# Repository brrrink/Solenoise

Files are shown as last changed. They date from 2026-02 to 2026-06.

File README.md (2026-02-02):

# Solenoise

## Overview

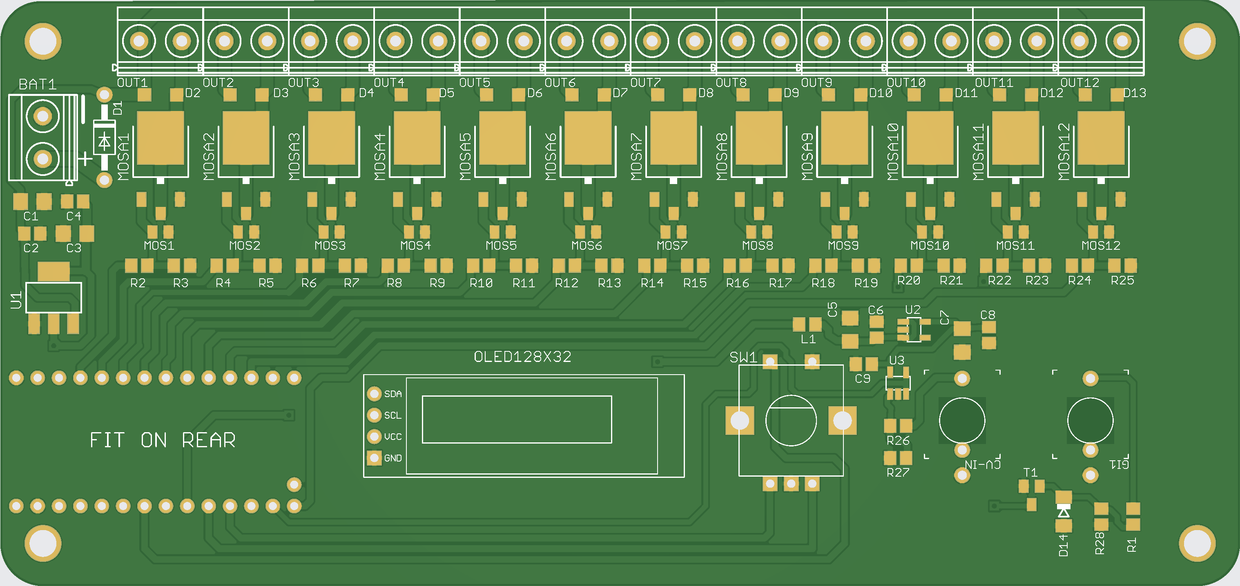
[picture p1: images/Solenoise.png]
solenoise


Solenoise is an open-source hardware and software system designed to transform everyday objects—such as metal plates, wooden surfaces, or architectural elements—into programmable percussive instruments. By leveraging solenoids as electromagnetic actuators, Solenoise enables automated performance, enhancing musical expressivity and extending human capabilities in experimental music, interactive installations, and architectural sound design.

The resurgence of analog modular synthesis, coupled with advancements in physical computing, has inspired this project. Traditional percussive instruments are limited by their fixed physical properties; Solenoise addresses this by providing a versatile control interface that bridges digital and physical realms.

## Key Features

- **Multi-Modal Input Control**: Supports class-compliant MIDI over TRS Mini-Jack, CV/gate inputs with internal logic for simplified and seamless integration with midi capable devices, modular synthesisers, and sequencers.
- **Hardware Simplicity**: Built around a Teensy 4.0 microcontroller with driverless MIDI input and simplified input protection circuits, ensuring compatibility with external devices.
- **Efficient Actuation**: Uses logic-level MOSFETs and protective transistors for safe and efficient operation of inductive loads (solenoids).
- **Configurable Software**: A flexible framework optimises latency and expressivity, with a focus on CV/Trigger input processing along with class compliant MIDI input.
- **Open-Source Ethos**: Unlike proprietary systems (e.g., Polyend Perc, Dada Machines Automat), Solenoise aims to democratise solenoid augmentation and aims to further collaborative innovation.

## Hardware Requirements

- **Microcontroller**: Teensy 4.0 (required for high-speed processing and MIDI support).
- **Solenoids**: Compatible 12V DC solenoids (e.g., push-pull types for striking objects).
- **Power Supply**: 12VDC Powers the development and the solenoids, with internal voltage protection and rectification.

### Input/Output

- **MIDI**: class-compliant MIDI (TRS Type A) via 3.175mm (1/8 inch) 'Mini Jack' input.
- **CV/Gate**: Analog inputs with protection circuits.

## Installation

- **Clone the repository**: git clone https://github.com/brrrink/Solenoise/solenoise.git
- cd solenoise
- Use Platformio to upload firmware to Teensy 4.0, hardware is available to purchase with pre-mounted SMD components or see the Solenoise Production Files folder, for all production ready design files.
- Upload these design files to the PCB manufacturer of your choice, who should be able to provide full soldered SMD PCB's from these files.
- A small number of through-hole components have to be added, these have been minimised to the degree possible to facilitate ease of construction.

## Usage

### Basic Setup

Attach solenoids to objects (e.g., via 3D-printed mounts—in progress enhancement).

Connect inputs:
- MIDI: Plug into a DAW or MIDI controller.
- Gates: Trigger via digital signals from sequencers.
- CV/Trigger: Use modular synth outputs for voltage-based control.

### Example: MIDI-Controlled Percussion

Send MIDI notes to Solenoise via Mini Jack (Type A).

### CV/Gate Integration

CV input controls the allocation of solenoid (12 in total)

Gate input will trigger discrete strikes, supplemented with MIDI for analog and moblie (battery powered) workflows.

### Performance Evaluation

Latency: <5ms for MIDI/CV processing (tested on Teensy 4.0).

Applications: Experimental music (e.g., hybrid human-robot performances), interactive art (e.g., responsive installations), sound design (e.g., architectural acoustics).

## Comparisons to Existing Systems

Solenoise builds on commercial and academic precedents but emphasises accessibility:

- **Commercial**: QRS PNOmation (piano retrofits), Polyend Perc (discontinued drumming machine), Dada Machines Automat (modular but costly), Koma Elektronik Field Kit (electroacoustic with solenoid control), Archil Lab Poet Pilot (object actuation).
- **Academic**: Logos Foundation <Vibi> (robotic vibraphone), Ajay Kapur's MahaDeviBot (percussion robot), Z-Machines guitar-bot.
- **Unique Aspects**: Open-source, CV/Gate inputs extend MIDI, driverless and mobile focussed design. 

## Future Enhancements

- 3D-printed solenoid mounts for easy attachment.
- Wireless control (e.g., via ESP32 integration).
- Expanded inputs/outputs for larger setups.
- Community-contributed presets and mappings.

## Contributing

Contributions are welcome! Fork the repo, create a branch, and submit a pull request. Focus areas:
- Bug fixes in firmware.
- New hardware variants (e.g., Eurorack compatibility).
- Documentation improvements.

Please follow the Code of Conduct.

## License

All non commercial use is approved.

Steal this code.

Commercial use is not approved without consent, contact the authour for more details: anon@anon.com

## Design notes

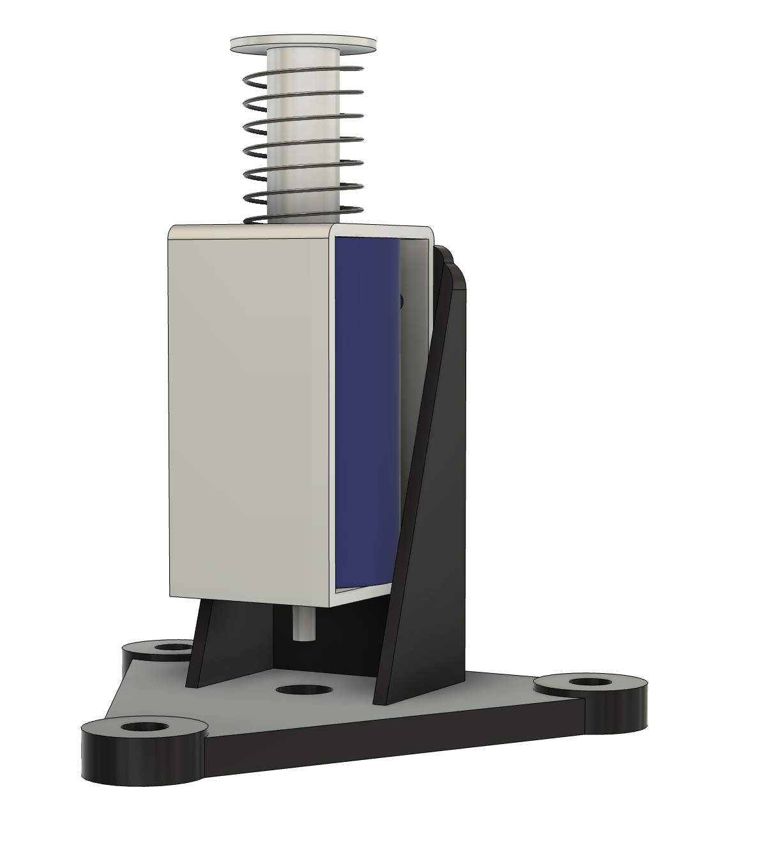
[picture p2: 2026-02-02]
Solenoise Connectors/Kinematic/Kinematic.png

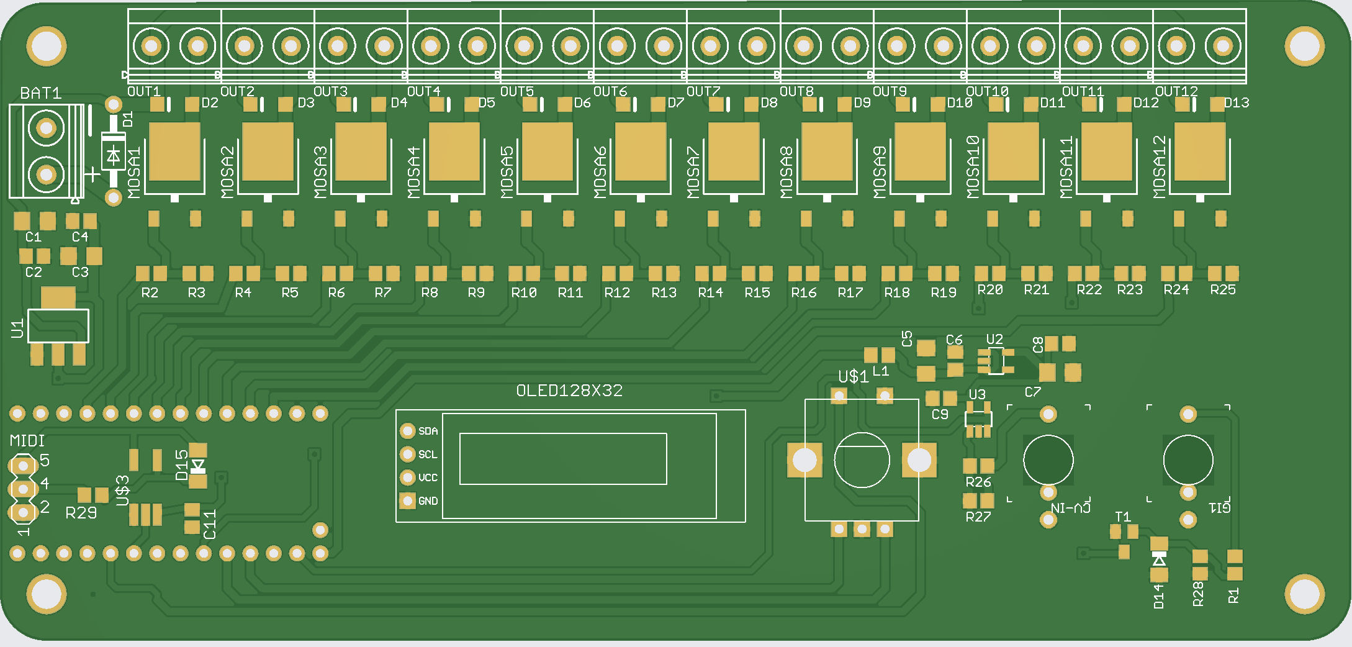
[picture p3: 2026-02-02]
PCB Front.png

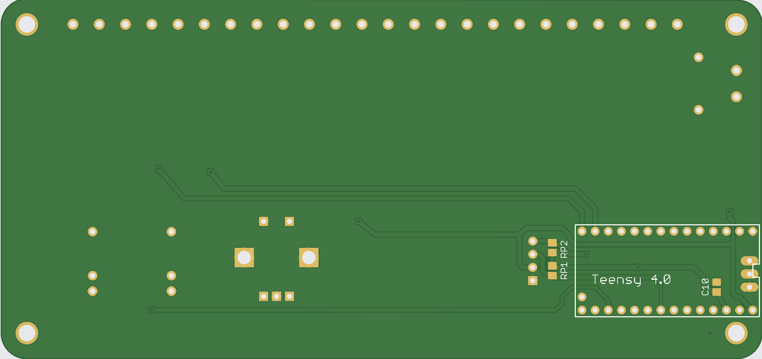
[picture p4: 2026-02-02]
PCB Rear.png

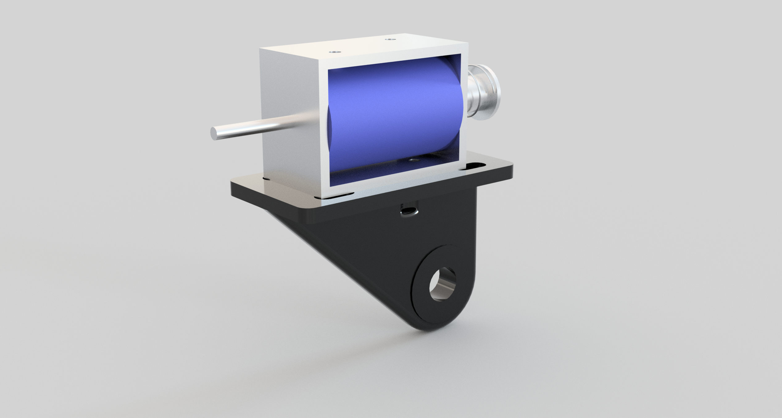
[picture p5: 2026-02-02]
Solenoise Connectors/Mic Clip/Mic Clip Small Render.png

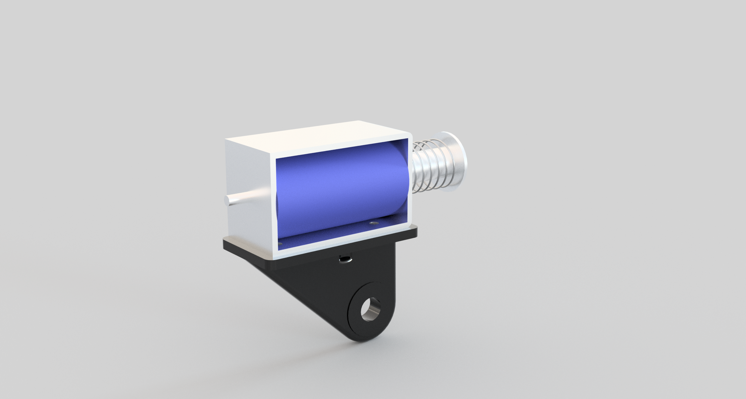
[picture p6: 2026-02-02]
Solenoise Connectors/Mic Clip/Mic Clip Large Render.png

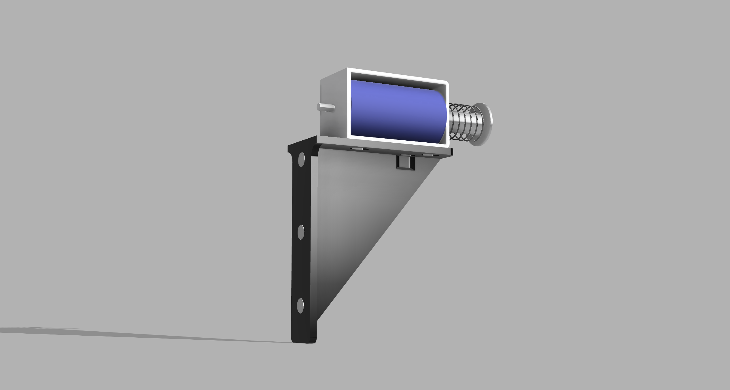
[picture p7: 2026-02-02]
Solenoise Connectors/Magnetic L/Magnetic L-Connector v0.png

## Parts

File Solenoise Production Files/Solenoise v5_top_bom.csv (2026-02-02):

Qty | Designator | Footprint | Comment | LCSC #
4 | C1, C3, C5, C7 | C1206 | 10u | C77092
6 | C2, C4, C6, C8, C9, C11 | C0805 | 100n | C28233
1 | C10 | C0805 | 470n | C13967
12 | D2, D3, D4, D5, D6, D7, D8, D9, D10, D11, D12, D13 | SOD123 | 1N5819HWQ | C460770
2 | D14, D15 | SOD80C | PMLL4148 | C78613
1 | L1 | R0805 | 10uH | C223171
12 | MOSA1, MOSA2,MOSA3, MOSA4, MOSA5, MOSA6, MOSA7, MOSA8, MOSA9, MOSA10, MOSA11, MOSA12 | FQD13N06LTM | FQD13N06LTM | C236914
15 | R1, R3, R5, R7, R9, R11,R13, R15, R17, R19, R21, R23, R25, R26, R28 | R0805 | 100k | C96346
13 | R2, R4, R6, R8, R10, R12, R14, R16, R18, R20, R22, R24, R29 | R0805 | 220R | C114519
1 | R30 | R0805 | 470R | C114564
1 | R27 | R0805 | 200K | C114235
1 | T1 | SOT23 | BC847 | C8664
1 | U$3 | SO-6-5 | TLP2361 | C6285467
1 | U1 | SOT223 | LM1117IMPX-5.0 | C41202
1 | U2 | SOT23-5 | ADP150-3.3 | C29149
1 | U3 | MCP6001 | MCP6001U | C21403

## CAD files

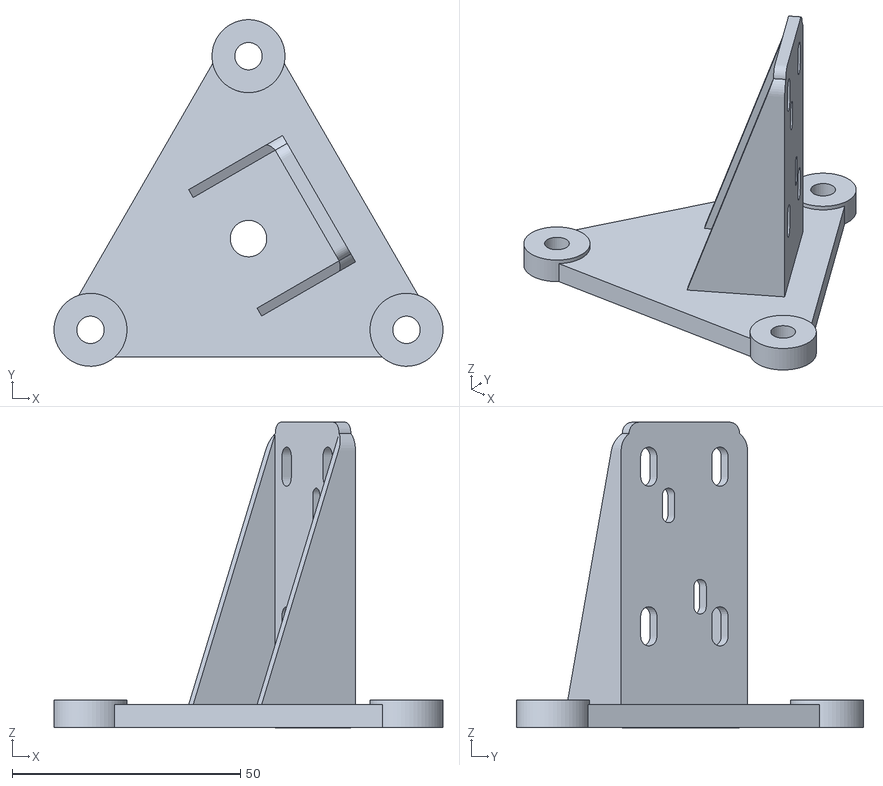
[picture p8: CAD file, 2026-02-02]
Solenoise Connectors/Kinematic/Kinematic Stand.stl
85.3 x 76.0 x 67.0

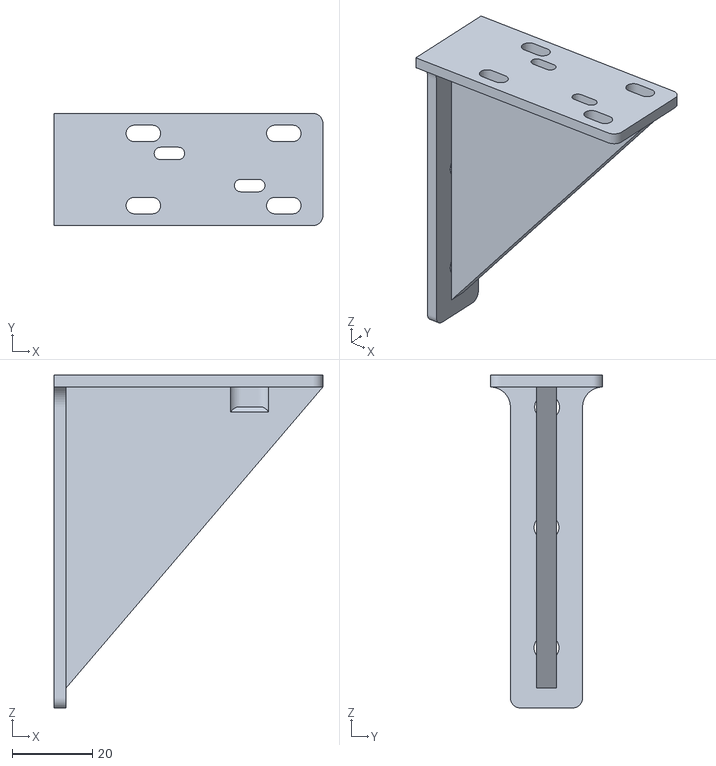
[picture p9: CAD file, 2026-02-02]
Solenoise Connectors/Magnetic L/Magnetic L-Connector.stl
67.0 x 28.0 x 83.0

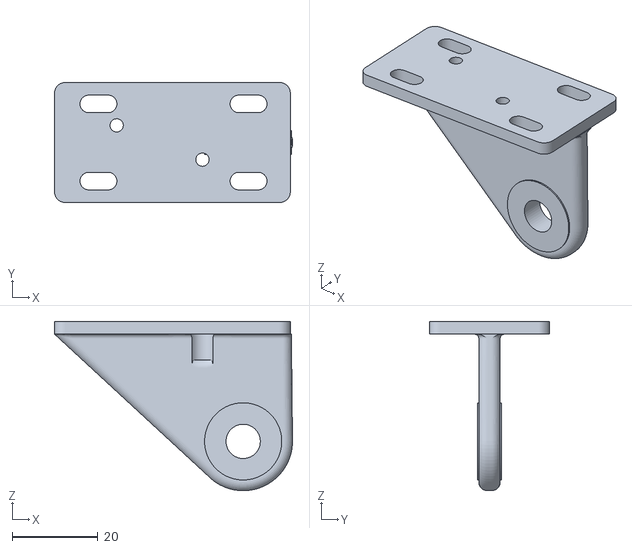
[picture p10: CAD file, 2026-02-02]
Solenoise Connectors/Mic Clip/Mic Clip v5.stl
55.5 x 28.0 x 39.5

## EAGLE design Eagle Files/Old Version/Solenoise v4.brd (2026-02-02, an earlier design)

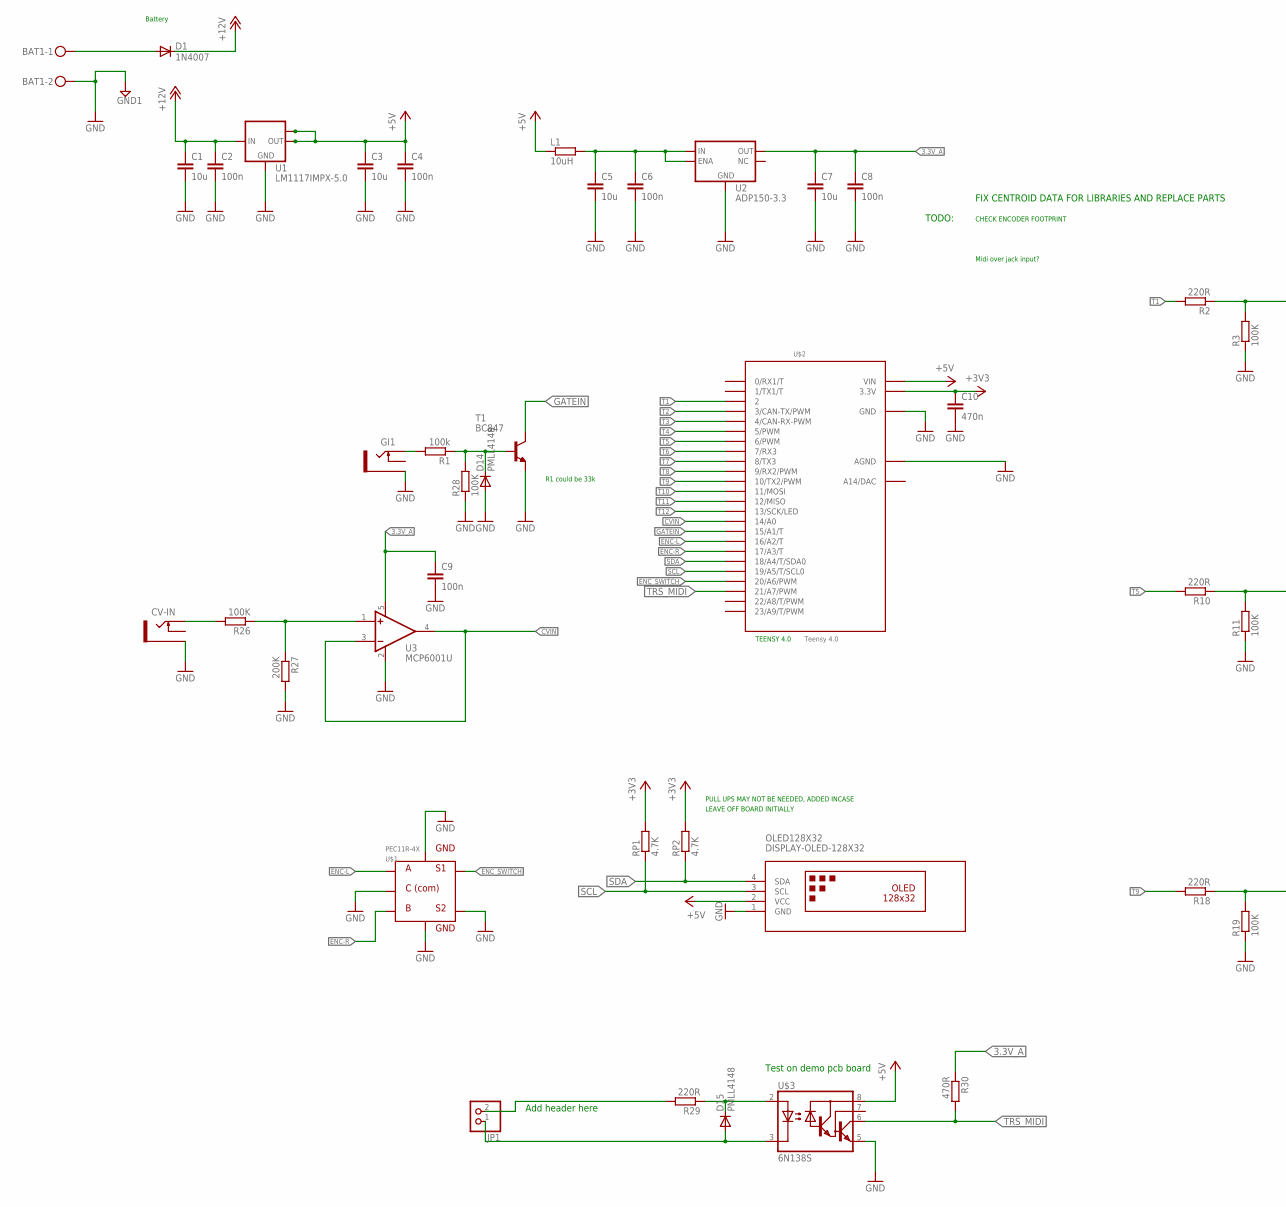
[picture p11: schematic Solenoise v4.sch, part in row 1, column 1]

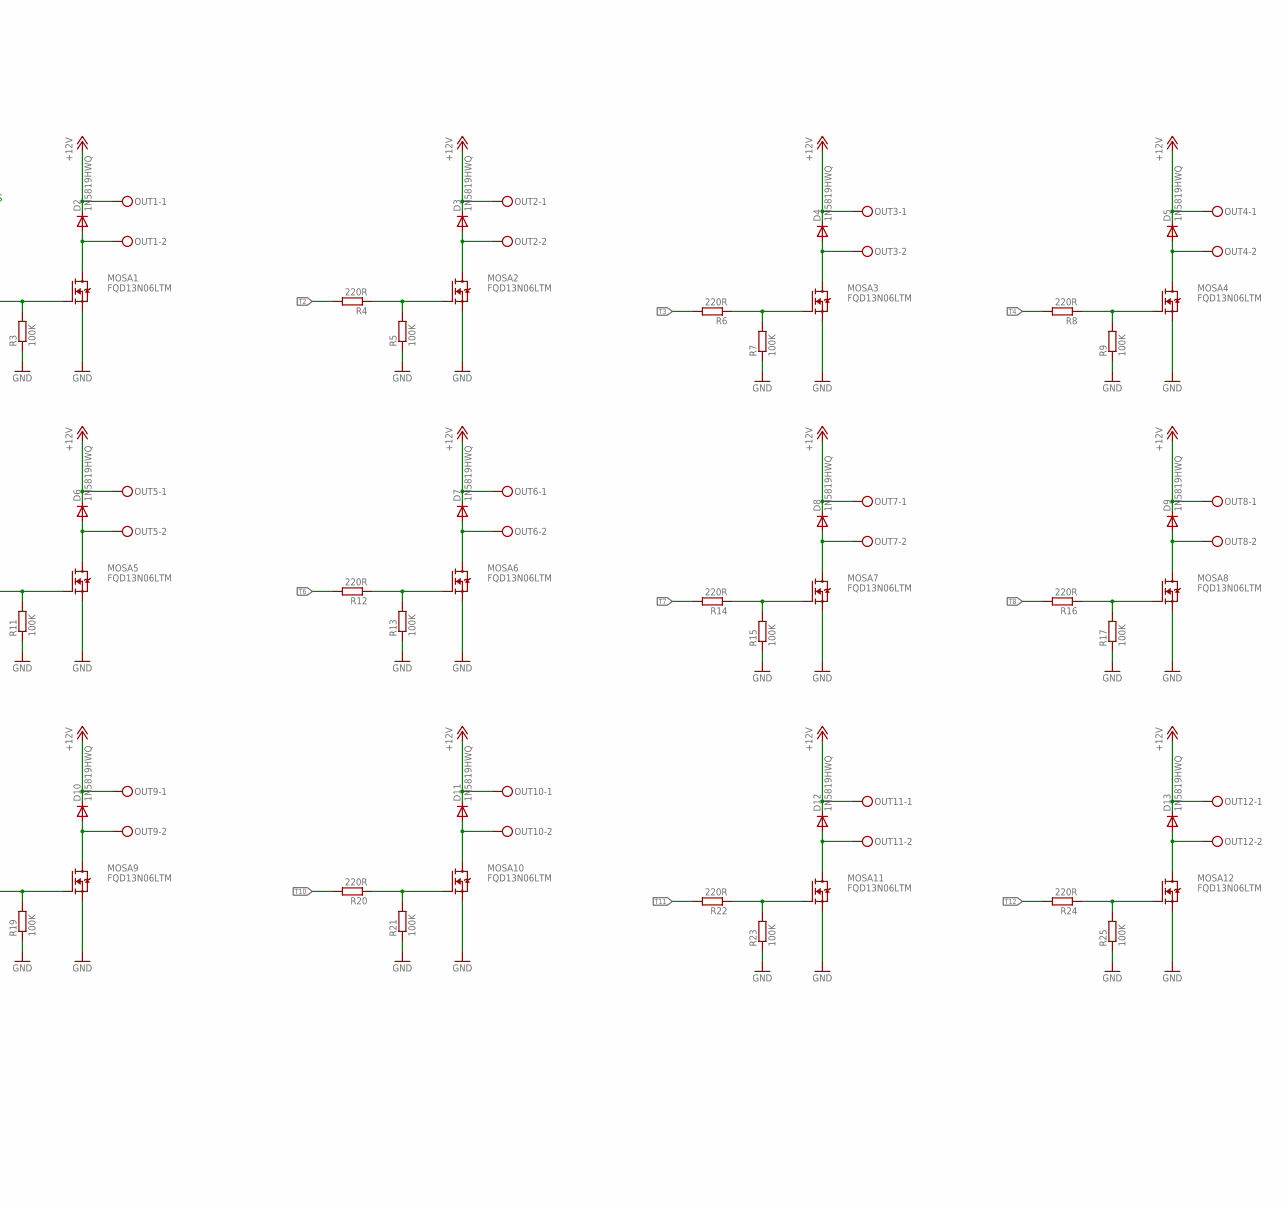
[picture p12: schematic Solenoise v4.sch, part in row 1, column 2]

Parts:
BAT1: MKDSN1,5/2-5,08
C1, C3, C5, C7: 10u; C1206
C2, C4, C6, C8, C9: 100n; C0805
C10: 470n; C0805
CV-IN: THONKICONNNEW; WQP-PJ301M-12_JACK
D1: 1N4007; DO41-10
D2, D3, D4, D5, D6, D7, D8, D9, D10, D11, D12, D13: 1N5819HWQ; SOD123
D14, D15: PMLL4148; SOD80C
GI1: THONKICONNNEW; WQP-PJ301M-12_JACK
JP1: PINHD-1X2; 1X02
L1: 10uH; R0805
MOSA1, MOSA2, MOSA3, MOSA4, MOSA5, MOSA6, MOSA7, MOSA8, MOSA9, MOSA10, MOSA11, MOSA12: FQD13N06LTM
OLED128X32: DISPLAY-OLED-128X32
OUT1, OUT2, OUT3, OUT4, OUT5, OUT6, OUT7, OUT8, OUT9, OUT10, OUT11, OUT12: MKDSN1,5/2-5,08
R1: 100k; R0805
R2, R4, R6, R8, R10, R12, R14, R16, R18, R20, R22, R24, R29: 220R; R0805
R3, R5, R7, R9, R11, R13, R15, R17, R19, R21, R23, R25, R26, R28: 100K; R0805
R27: 200K; R0805
R30: 470R; R0805
RP1, RP2: 4.7K; R0805
T1: BC847; SOT23
U1: LM1117IMPX-5.0; SOT223
U2: ADP150-3.3; SOT23-5
U3: MCP6001U; MCP6001
U$1: PEC11R-4X; ENC
U$2: Teensy 4.0; TEENSY_3.1_DAC
U$3: 6N138S

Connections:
3.3V_A: C7.1, C8.1, C9.1, R30.1, U2.OUT (VOUT), U3.5 (V+)
+3V3: C10.1, RP1.2, RP2.2, U$2.3.3V
+5V: C3.1, C4.1, L1.1, OLED128X32.2 (VCC), U1.2 (OUT), U1.TAB (OUT1), U$2.VIN, U$3.8 (VCC)
+12V: C1.1, C2.1, D1.C, D2.C, D3.C, D4.C, D5.C, D6.C, D7.C, D8.C, D9.C, D10.C, D11.C, D12.C, D13.C, OUT1.1, OUT2.1, OUT3.1, OUT4.1, OUT5.1, OUT6.1, OUT7.1, OUT8.1, OUT9.1, OUT10.1, OUT11.1, OUT12.1, U1.3 (IN)
CVIN: U3.3 (-IN), U3.4 (OUT), U$2.14/A0
ENC-L: U$1.A, U$2.16/A2 (16/A2/T)
ENC-R: U$1.B, U$2.17/A3 (17/A3/T)
ENC_SWITCH: U$1.1 (SW1), U$2.20/A6 (20/A6/PWM)
GATEIN: T1.3 (C), U$2.15/A1 (15/A1/T)
GND: BAT1.2, C1.2, C2.2, C3.2, C4.2, C5.2, C6.2, C7.2, C8.2, C9.2, C10.2, CV-IN.P$3_SLEEVE (SLEEVE), D14.A, GI1.P$3_SLEEVE (SLEEVE), MOSA1.2 (S), MOSA2.2 (S), MOSA3.2 (S), MOSA4.2 (S), MOSA5.2 (S), MOSA6.2 (S), MOSA7.2 (S), MOSA8.2 (S), MOSA9.2 (S), MOSA10.2 (S), MOSA11.2 (S), MOSA12.2 (S), OLED128X32.1 (GND), R3.1, R5.1, R7.1, R9.1, R11.1, R13.1, R15.1, R17.1, R19.1, R21.1, R23.1, R25.1, R27.2, R28.1, T1.2 (E), U1.1 (GND), U2.GND, U3.2 (V-), U$1.2 (SW2), U$1.C, U$1.GND1, U$1.GND2, U$2.AGND, U$2.GND, U$3.5 (GND)
MOS1.1: D2.A, MOSA1.3 (D), OUT1.2
MOS1.2: D3.A, MOSA2.3 (D), OUT2.2
MOS1.3: D4.A, MOSA3.3 (D), OUT3.2
MOS1.4: D5.A, MOSA4.3 (D), OUT4.2
MOS1.5: D6.A, MOSA5.3 (D), OUT5.2
MOS1.6: D7.A, MOSA6.3 (D), OUT6.2
MOS1.7: D8.A, MOSA7.3 (D), OUT7.2
MOS1.8: D9.A, MOSA8.3 (D), OUT8.2
MOS1.9: D10.A, MOSA9.3 (D), OUT9.2
MOS1.10: D11.A, MOSA10.3 (D), OUT10.2
MOS1.11: D12.A, MOSA11.3 (D), OUT11.2
MOS1.12: D13.A, MOSA12.3 (D), OUT12.2
unnamed: R26.1, R27.1, U3.1 (+IN)
unnamed: MOSA1.1 (G), R2.1, R3.2
unnamed: MOSA2.1 (G), R4.1, R5.2
unnamed: MOSA3.1 (G), R6.1, R7.2
unnamed: CV-IN.P$1_TIP (TIP), R26.2
unnamed: C5.1, C6.1, L1.2, U2.EN (ENA), U2.VIN (IN)
unnamed: MOSA4.1 (G), R8.1, R9.2
unnamed: MOSA5.1 (G), R10.1, R11.2
unnamed: MOSA6.1 (G), R12.1, R13.2
unnamed: MOSA7.1 (G), R14.1, R15.2
unnamed: MOSA8.1 (G), R16.1, R17.2
unnamed: MOSA9.1 (G), R18.1, R19.2
unnamed: MOSA10.1 (G), R20.1, R21.2
unnamed: MOSA11.1 (G), R22.1, R23.2
unnamed: MOSA12.1 (G), R24.1, R25.2
unnamed: BAT1.1, D1.A
unnamed: GI1.P$1_TIP (TIP), R1.2
unnamed: D14.C, R1.1, R28.2, T1.1 (B)
unnamed: D15.C, R29.1, U$3.2 (A)
unnamed: D15.A, JP1.1, U$3.3 (C)
unnamed: JP1.2, R29.2
SCL: OLED128X32.3 (SCL), RP1.1, U$2.19/A5 (19/A5/T/SCL0)
SDA: OLED128X32.4 (SDA), RP2.1, U$2.18/A4 (18/A4/T/SDA0)
T1: R2.2, U$2.2
T2: R4.2, U$2.3 (3/CAN-TX/PWM)
T3: R6.2, U$2.4 (4/CAN-RX-PWM)
T4: R8.2, U$2.5 (5/PWM)
T5: R10.2, U$2.6 (6/PWM)
T6: R12.2, U$2.7 (7/RX3)
T7: R14.2, U$2.8 (8/TX3)
T8: R16.2, U$2.9 (9/RX2/PWM)
T9: R18.2, U$2.10 (10/TX2/PWM)
T10: R20.2, U$2.11 (11/MOSI)
T11: R22.2, U$2.12 (12/MISO)
T12: R24.2, U$2.13 (13/SCK/LED)
TRS_MIDI: R30.2, U$2.21/A7 (21/A7/PWM), U$3.6 (VO)

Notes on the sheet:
TODO:
R1 could be 33k
PULL UPS MAY NOT BE NEEDED, ADDED INCASE
LEAVE OFF BOARD INITIALLY
CHECK ENCODER FOOTPRINT
TEENSY 4.0
Battery
Midi over jack input?
FIX CENTROID DATA FOR LIBRARIES AND REPLACE PARTS
Add header here
Test on demo pcb board

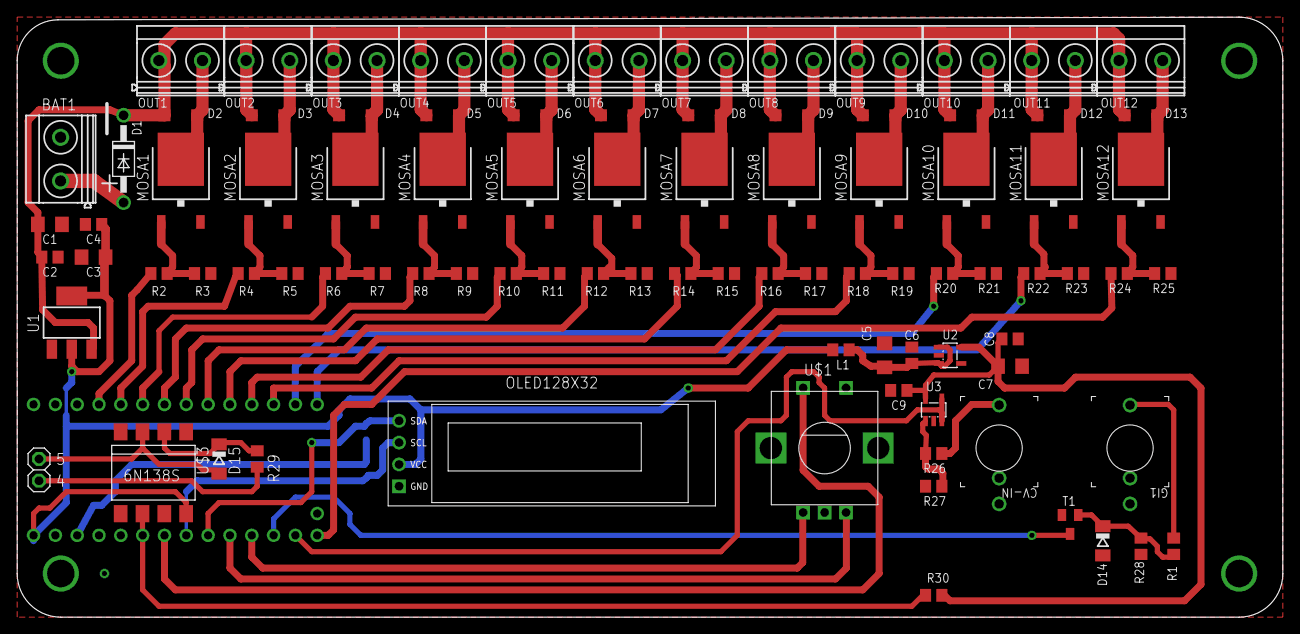
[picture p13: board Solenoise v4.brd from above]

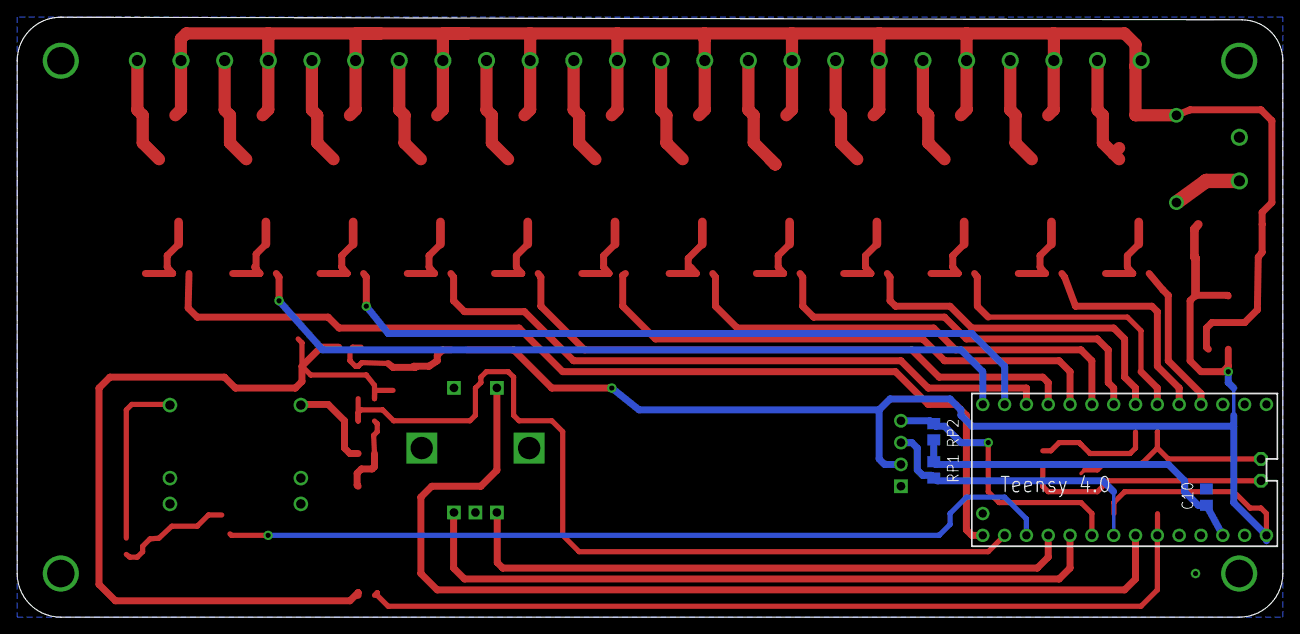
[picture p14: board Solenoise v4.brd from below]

Board: 2 copper layers, 147.3 x 69.8 mm, 94 parts (4 on the bottom side), 58 nets.

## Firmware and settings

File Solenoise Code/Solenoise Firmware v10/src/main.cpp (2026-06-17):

//---------------------- Solenoise Firmware Testing v10 -------------------------//
//----------------------------- John Harding -----------------------------------//
//---------------------------- Steal This Code ---------------------------------//


// Teensy 4 Pins:
// - OLED display on I2C address 0x3C
// - For Teensy 4: SDA on pin 18, SCL on pin 19
// - Encoder pins: Enc-L (A) on pin 16 (A2), Enc-R (B) on pin 17 (A3)
// - Encoder switch on pin 22
// - MIDI RX on pin 21 (Serial 5)
// - CV input 0-5V is on pin 14(A0)
// - Gate input 0-5V is on pin 15 (A1)
// - Transistor outputs T1 to T12 are on pins 2 - 13

// - MIDI TRS input using TLP2361 opto-isolator connected to pin 21 (RX5 for Serial5)
//   (TX5 on pin 20 is unused)
// - On the PCB Silkscreen, Pin 4 (bottom left-hand side of pcb) is the Midi input pin, Pin: 5 is the GND pin.
// - For TRS MIDI Type A (Tip: Pin 5, Ring: Pin 4, Sleeve: GND)

// - Testing:
// - Adding Encoder input for actuator on time plus gate delay (delays gate read to allow CV to settle)

// Teensy 4 Pins:
// - OLED display on I2C address 0x3C
// - For Teensy 4: SDA on pin 18, SCL on pin 19
// - Encoder pins: Enc-L (A) on pin 16 (A2), Enc-R (B) on pin 17 (A3)
// - Encoder switch on pin 22
// - MIDI RX on pin 21 (Serial 5)
// - CV input 0-5V is on pin 14(A0)
// - Gate input 0-5V is on pin 15 (A1)
// - Transistor outputs T1 to T12 on pins 2 - 13


//----------------------INCLUDES----------------------------//
#include <Arduino.h>
#include <Wire.h>
#include <Adafruit_SSD1306.h>
#include <Encoder.h>
#include <MIDI.h>
//---------------------------------------------------------//

//-----------------------CONSTANTS-------------------------//
#define OLED_RESET 4
Adafruit_SSD1306 display(OLED_RESET);

#define SCREEN_WIDTH 128
#define SCREEN_HEIGHT 32

#if (SSD1306_LCDHEIGHT != 32)
#error("Height incorrect, please fix Adafruit_SSD1306.h!");
#endif

#define ENCODER_SWITCH_PIN 22
#define CV_PIN 14
#define GATE_PIN 15
#define PPR 24
#define CPR (PPR * 4)

const bool INVERT_ENCODER = true;

const char* noteNames[] = {"C", "C#", "D", "D#", "E", "F", "F#", "G", "G#", "A", "A#", "B"};

#define MIDI_NOTE_START 36
#define MIDI_NOTE_END 47
#define OUTPUT_PIN_START 2

#define DISPLAY_UPDATE_INTERVAL 50
#define SWITCH_DEBOUNCE_MS 50

#define SETTLE_MIN_US 50
#define SETTLE_MAX_US 500
#define PULSE_MIN_MS 20
#define PULSE_MAX_MS 50

//---------------------------------------------------------//

//-----------------------VARIABLES-------------------------//
Encoder enc(16, 17);

bool switchState = false;
int lastButtonState = HIGH;
int debouncedButtonState = HIGH;
unsigned long lastDebounceTime = 0;

int cv_value = 0;
int gate_state = HIGH;
int last_gate_state = HIGH;

int last_note = -1;
int last_vel = 0;

unsigned long lastDisplayUpdate = 0;
bool displayNeedsUpdate = true;

unsigned long pulseStartTimes[12] = {0};

int settleDelayUS = 200;
int pulseDuration = 30;

int editMode = 0;            // 0 = normal, 1 = settle delay, 2 = pulse duration
long lastEncoderPosition = 0;

//---------------------------------------------------------//

MIDI_CREATE_INSTANCE(HardwareSerial, Serial5, midiIn);
//---------------------------------------------------------//

void setup() {
  Serial.begin(9600);
  Wire.begin();

  display.begin(SSD1306_SWITCHCAPVCC, 0x3C);
  display.setRotation(0);
  display.clearDisplay();
  display.setTextSize(1);
  display.setTextColor(WHITE);

  pinMode(ENCODER_SWITCH_PIN, INPUT_PULLUP);
  pinMode(GATE_PIN, INPUT_PULLUP);

  for (int pin = OUTPUT_PIN_START; pin < OUTPUT_PIN_START + 12; pin++) {
    pinMode(pin, OUTPUT);
    digitalWrite(pin, LOW);
  }

  Serial5.begin(31250);
  midiIn.begin(MIDI_CHANNEL_OMNI);
  midiIn.turnThruOff();

  LPUART5_CTRL &= ~(1UL << 19);

  lastEncoderPosition = enc.read();
}

void handleMIDI() {
  while (midiIn.read()) {
    byte type = midiIn.getType();
    int note = midiIn.getData1();
    int vel = midiIn.getData2();

    if (type == midi::NoteOn || type == midi::NoteOff) {
      bool isOn = (type == midi::NoteOn && vel > 0);
      if (!isOn) vel = 0;

      last_note = note;
      last_vel = vel;
      displayNeedsUpdate = true;

      if (note >= MIDI_NOTE_START && note <= MIDI_NOTE_END && isOn) {
        int index = note - MIDI_NOTE_START;
        digitalWrite(OUTPUT_PIN_START + index, HIGH);
        pulseStartTimes[index] = millis();
      }
    }
  }
}

void checkPulseTimers() {
  unsigned long now = millis();
  for (int i = 0; i < 12; i++) {
    if (pulseStartTimes[i] != 0 && now - pulseStartTimes[i] >= pulseDuration) {
      digitalWrite(OUTPUT_PIN_START + i, LOW);
      pulseStartTimes[i] = 0;
      displayNeedsUpdate = true;
    }
  }
}

void handleCVGate() {
  gate_state = digitalRead(GATE_PIN);

  if (last_gate_state == HIGH && gate_state == LOW) {
    unsigned long startWait = micros();
    while (micros() - startWait < settleDelayUS) {
      handleMIDI();
    }

    cv_value = analogRead(CV_PIN);

    int index = (cv_value * 12) / 1024;

    digitalWrite(OUTPUT_PIN_START + index, HIGH);
    pulseStartTimes[index] = millis();

    displayNeedsUpdate = true;
  }

  last_gate_state = gate_state;
}

void readInputs() {
  long raw_position = enc.read();
  long position = INVERT_ENCODER ? -raw_position : raw_position;

  if (editMode != 0) {
    long delta = position - lastEncoderPosition;
    if (delta != 0) {
      if (editMode == 1) {
        pulseDuration = constrain(pulseDuration + delta, PULSE_MIN_MS, PULSE_MAX_MS);
      } else if (editMode == 2) {
        settleDelayUS = constrain(settleDelayUS + delta * 10, SETTLE_MIN_US, SETTLE_MAX_US);
      }
      displayNeedsUpdate = true;
      lastEncoderPosition = position;
    }
  } else {
    lastEncoderPosition = position;
  }

  int reading = digitalRead(ENCODER_SWITCH_PIN);
  if (reading != lastButtonState) {
    lastDebounceTime = millis();
  }
  if ((millis() - lastDebounceTime) > SWITCH_DEBOUNCE_MS) {
    if (reading != debouncedButtonState) {
      debouncedButtonState = reading;
      if (debouncedButtonState == LOW) {
        editMode = (editMode + 1) % 3;
        displayNeedsUpdate = true;
      }
    }
  }
  lastButtonState = reading;

  handleCVGate();
}

void updateDisplay() {
  display.clearDisplay();

  // Top line - base labels (always visible)
  display.setCursor(0, 0);
  display.setTextColor(WHITE);
  display.print("On:");
  display.setCursor(28, 0);           // Position after "On:"
  display.print(pulseDuration);
  display.print("ms");

  display.setCursor(68, 0);
  display.print("Del:");
  display.setCursor(96, 0);           // Position after "Del:"
  display.print(settleDelayUS);
  display.print("us");

  // Highlight pulse duration value
  if (editMode == 1) {
    display.fillRect(28, 0, 38, 8, WHITE);   // Box around "30ms"
    display.setTextColor(BLACK);
    display.setCursor(28, 0);
    display.print(pulseDuration);
    display.print("ms");
    display.setTextColor(WHITE);
  }

  // Highlight settle delay value
  if (editMode == 2) {
    display.fillRect(96, 0, 32, 8, WHITE);   // Box around "200us"
    display.setTextColor(BLACK);
    display.setCursor(96, 0);
    display.print(settleDelayUS);
    display.print("us");
    display.setTextColor(WHITE);
  }

  // CV/Gate line
  display.setCursor(0, 8);
  display.print("CV: ");
  float voltage = (cv_value * 5.0f) / 1024.0f;
  display.print(voltage, 2);
  display.print("V -> ");
  int step = (cv_value * 12) / 1024;
  display.print(step + 1);

  if (gate_state == LOW) {
    display.fillRect(118, 8, 8, 8, WHITE);
  } else {
    display.drawRect(118, 8, 8, 8, WHITE);
  }

  // MIDI line
  display.setCursor(0, 16);
  display.print("Note: ");
  if (last_note != -1) {
    display.print(last_note);
    int note_mod = last_note % 12;
    int octave = (last_note / 12) - 1;
    display.print(" (");
    display.print(noteNames[note_mod]);
    display.print(octave);
    display.print(")");
  } else {
    display.print("None");
  }

  if (last_vel > 0) {
    display.fillRect(118, 16, 8, 8, WHITE);
  } else {
    display.drawRect(118, 16, 8, 8, WHITE);
  }

  // Output status
  for (int i = 0; i < 12; i++) {
    int x = i * 10;
    if (pulseStartTimes[i] != 0) {
      display.fillRect(x, 24, 8, 8, WHITE);
    } else {
      display.drawRect(x, 24, 8, 8, WHITE);
    }
  }

  display.display();
  displayNeedsUpdate = false;
  lastDisplayUpdate = millis();
}

void loop() {
  handleMIDI();
  checkPulseTimers();
  readInputs();

  unsigned long now = millis();
  if (displayNeedsUpdate || (now - lastDisplayUpdate >= DISPLAY_UPDATE_INTERVAL)) {
    updateDisplay();
  }

  handleMIDI();
}

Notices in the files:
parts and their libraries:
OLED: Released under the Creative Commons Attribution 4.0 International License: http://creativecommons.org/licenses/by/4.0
